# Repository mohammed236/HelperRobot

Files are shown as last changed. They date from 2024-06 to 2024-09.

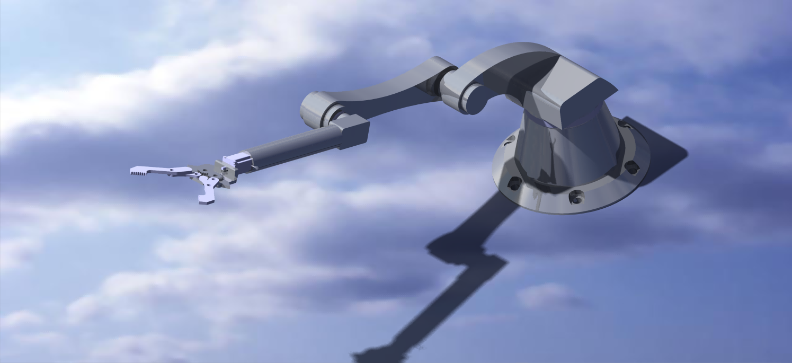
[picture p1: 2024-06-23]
Assets for Presentation/Systeme Image 2.tif

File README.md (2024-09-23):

# HelperRobot
Building a robot that can perform different tasks in various use cases.

# About
This project is a BTS graduation project. As mechanical product designers, we had to create a mechatronic mechanism to enhance our knowledge.

# Help
This project contains different file extensions for various software used. You will need:
* Microsoft Word
* Gantt, Trello, Excel
* Catia V5
* WonderShare EdrawMax
* Proteus
* Arduino IDE 2.0.3

# Note
This project is not completed.

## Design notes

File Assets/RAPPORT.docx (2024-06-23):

I. Analyse Fonctionnelle :

II. Analyse statique :

L’étude statique c’est l’étude des solides au repos (stable) pour un temps donné. Cette étude sert à déterminer les couples nécessaires pour actionner les articulations de notre bras manipulateur aussi que les efforts et les moments exercé au niveau du chaque articulations.

1. Schéma cinématique :

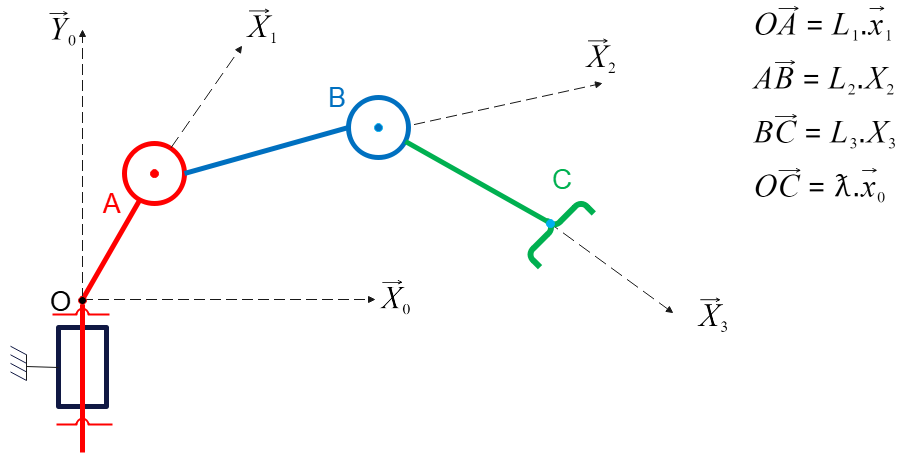
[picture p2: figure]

Repère | Solide | Paramètre | Dimension
0 | Châssis | XXXX | XXXX
1 | Bras articulé 1 | 0< θ_1 <360 | 90 mm
2 | Bras articulé 2 | -70< θ_2 <180 | 124 mm
3 | Bras articulé 3 | -160< θ_3 <160 | 135 mm

2. Les figures planes :

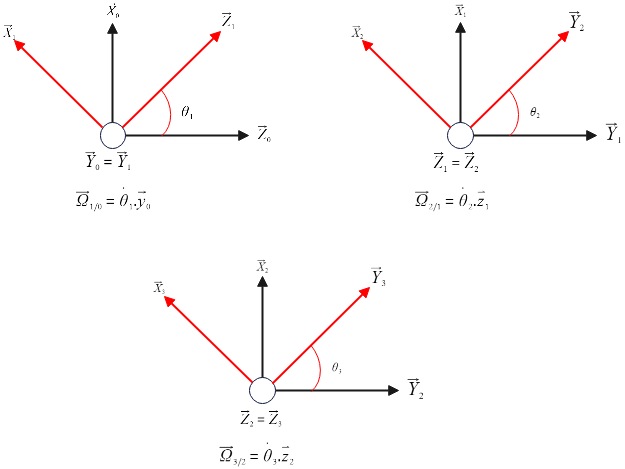
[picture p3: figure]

3. Graphe de structure :

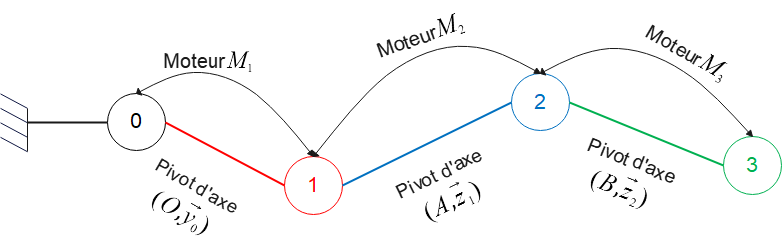
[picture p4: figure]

4. Hyperstatisme :

L'hyperstatisme, également connu sous le terme d'hyperstaticité ou de redondance statique, se réfère à une situation dans laquelle une structure possède plus de contraintes externes ou internes qu'il n'est nécessaire pour maintenir son équilibre statique. En d'autres termes, c'est une situation où il y a plus de liaisons ou de supports que ce qui est strictement nécessaire pour garantir la stabilité et la rigidité de la structure.

4.1. Objectifs et Avantages de l'Hyperstatisme :

4.1.1. Redondance Structurelle :

- Sécurité : En cas de défaillance d'un ou plusieurs éléments, la structure peut encore rester stable et en sécurité grâce aux liaisons supplémentaires. Cela est particulièrement important dans les ponts, les bâtiments et d'autres infrastructures critiques.

- Durabilité : Les structures hyperstatiques répartissent les charges de manière plus uniforme, réduisant les concentrations de stress et prolongeant ainsi la durée de vie des matériaux.

4.1.2. Rigidité Accrue :

- Déformations Réduites : Les structures hyperstatiques tendent à être plus rigides et moins sujettes aux déformations sous des charges, ce qui est crucial pour maintenir la fonctionnalité et l'intégrité de la structure.

4.1.3. Optimisation des Matériaux :

- Efficacité Matérielle : En concevant des structures hyperstatiques, les ingénieurs peuvent souvent utiliser les matériaux de manière plus efficace, répartissant les charges de manière à minimiser l'utilisation de matériaux tout en maximisant la performance structurale.

4.2. Exemples d'Applications :

4.2.1. Ponts : Les ponts sont souvent conçus avec une redondance statique pour garantir qu'ils restent en place même si une partie de la structure subit des dommages.

4.2.2. Bâtiments : Les gratte-ciels et autres grandes structures intègrent souvent des éléments hyperstatiques pour assurer leur stabilité face aux vents, aux tremblements de terre et à d'autres forces dynamiques.

4.2.3. Aéronautique : Dans les avions, la redondance est cruciale pour garantir la sécurité en cas de défaillance d'un composant.

En Résume :

L'hyperstatisme est une approche de conception qui vise à améliorer la sécurité, la durabilité et la performance des structures en ajoutant des liaisons ou des supports supplémentaires au-delà de ce qui est strictement nécessaire pour l'équilibre statique. Cela permet de créer des structures plus robustes, capables de résister à des défaillances locales sans compromettre leur intégrité globale.

4.3. Calcule de l'hyperstatisme :

L'hyperstatisme se calcule en examinant la différence entre les contraintes introduites par les moteurs et les degrés de liberté nécessaires pour un mouvement indépendant.

- Si m est la mobilité de system, alors : m = Mu + Mi = 3 + 0 = 3

Alors, m = 3

- L'hyperstatisme H peut être calculé comme :

H = Is – 6 * (nb pieces hors bati) + m

H = 15 – 6 * 3 + 3

H = 15 – 18 + 3 = 0

Donc, H = 0

Dans ce cas, le système n'est pas hyperstatique. Si H était supérieur à zéro, cela indiquerait un système hyperstatique (redondance statique).

### Ce résultat est confirmé par le fait que tous les systèmes ouverts sont isostatiques.

### 4.3.1 Conclusion

Le système décrit ici est isostatique avec H=0, ce qui signifie qu'il est exactement déterminé avec le nombre de moteurs et d'articulations disponibles.

### 4.4. mouvement de la pince / analyse cinématique

### 4.4.1 détermination de loi entrer sotie du système

### Pour monter la méthode de détermination de loi entrer sotie du system, on va d’abord simplifier le system comme suivant :

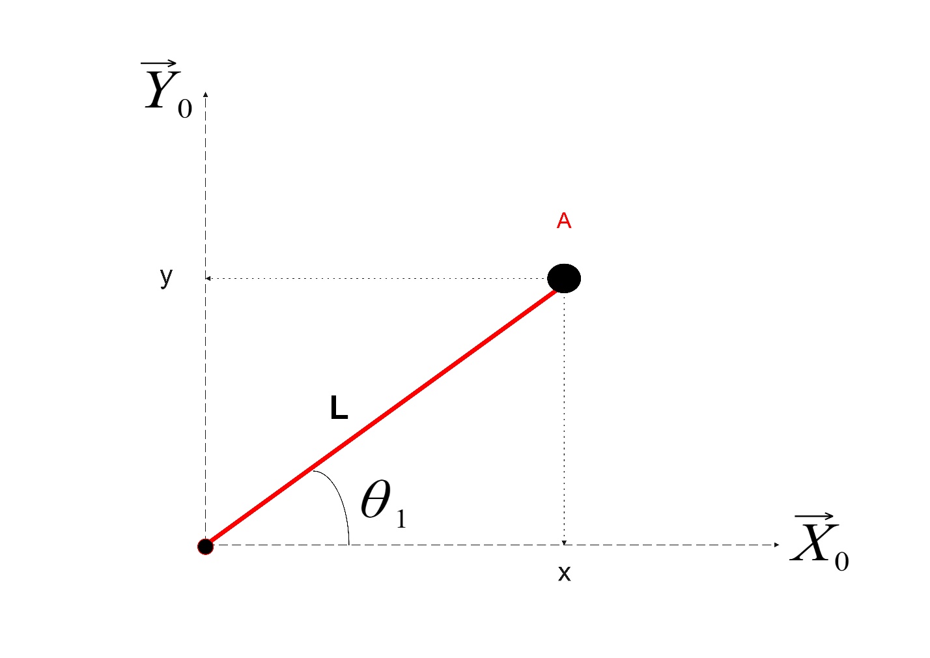
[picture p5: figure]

### En va prendre deux équations de cette figure pour déterminer l’angle θ1 par laquelle le point A sera déplacer.

### Première équation :

### L^2 = x^2 + y^2

### L= √(x^2 +y^2)

### Deuxième équation :

### tanθ1= y/x

### θ1= tan^(-1) y/x

### L’utilité de la première équation dans ce cas est de vérifier que la position a atteindre et ce qui il est dans la zone du bras ou non.

### Par exemple :

### On demande que le point A se déplace vers (30 ,10), avec la langueur du bras est

### L = 5

### Pour vérifier la position désirée on calcule :

### ( √(30^2 +10^2)<= 5 ) ?

### Si oui donc on peut se déplace et le point est dans la zone de déplacement du bras.

### Si non donc le point est hors la zone de déplacement du bras.

### Alors par la même approche en va ajouter un deuxième bras dans la figure comme dans la figure ci-dessous et pour simplifier L’étude on prendre que

### (L2 = L3) de notre system :

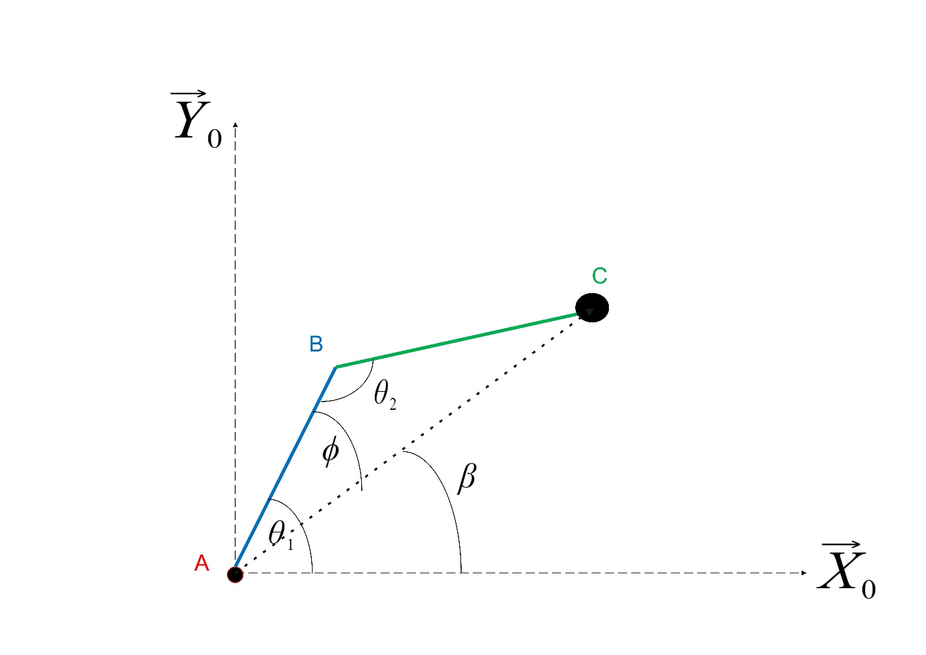
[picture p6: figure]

### Cette figure nos donnera les équations suivantes :

### tanβ= y/x

### β= tan^(-1) y/x

### Et on a d’après la loi de cosinus :

### L2^2 =L1^2 +L^2 -2L1.L.cosϕ

### cosϕ= (L1^2 +L^2 - L2^2)/(2L1.L)

### ϕ= cos^(-1) (L1^2 +L^2 - L2^2)/(2L1.L)

Alors :

Θ1 = ϕ + β = cos^(-1) (L1^2 +L^2 - L2^2)/(2L1.L)+ tan^(-1) y/x

Et On a de même :

L^2 =L1^2 +L2^2 -2L1.L2.cosΘ2

### cosΘ2= (L1^2 -L^2 + L2^2)/(2L1.L2)

### Θ2= cos^(-1) (L1^2 -L^2 + L2^2)/(2L1.L2)

### Finalement : {, Θ1= cos^(-1) (L1^2 +L^2 - L2^2)/(2L1.L)+ tan^(-1) y/x, Θ2 = cos^(-1) (L1^2 -L^2 + L2^2)/(2L1.L2)

Maintenant on a les valeurs nécessaires pour déplacer la pince par des angles effectuer par des moteurs.
mais dans notre cas on a le premier bras est fixe sur le bâti par un angle K1 dans l’axe Z. et ce bras effectuer une rotation sur l’axe Y commandée par un moteur d’angle Θ0 (voir figure ci-dessous).

et pour ajouter le premier bras dans notre analyse en vas traiter la premier plan (X, Y) comme suivant :

Le premier bras dans ce system est considérer comme un déplacement du repère du deux bras 1 et 2 par rapport au repère R0.
Alors pour trouver les relations finales des paramètres d’enter pour le déplacement de pince sur le plan (X, Y), il suffit de soustraire les coordonner de position de la pince et les coordonner du point A du system pour se retourner dans le cas étudie précédent.
avec cette approche la seule variable qui sera changée est le module L du système.

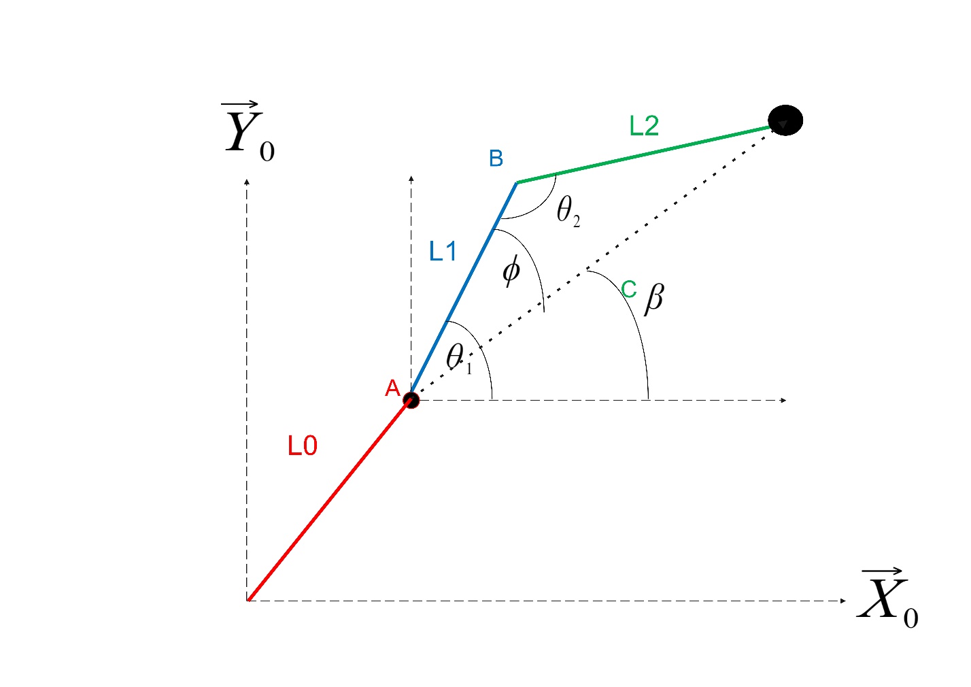
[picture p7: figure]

### On pose (Xi, Yi) les coordonner du point A, et (x, y) sont les coordonner de la pince, et que le premier bras est orienté par 65 dégrée sur l’axe Z donc :

### Xi=L0.cos65

### Yi=L0.sin65

### Alors :

### L= √((x-Xi)^2 +(y-Yi)^2)

### Maintenant il suffit de trouver l’angle Θ0 pour compléter notre étude sur la Cinématique Inversée de la pince.

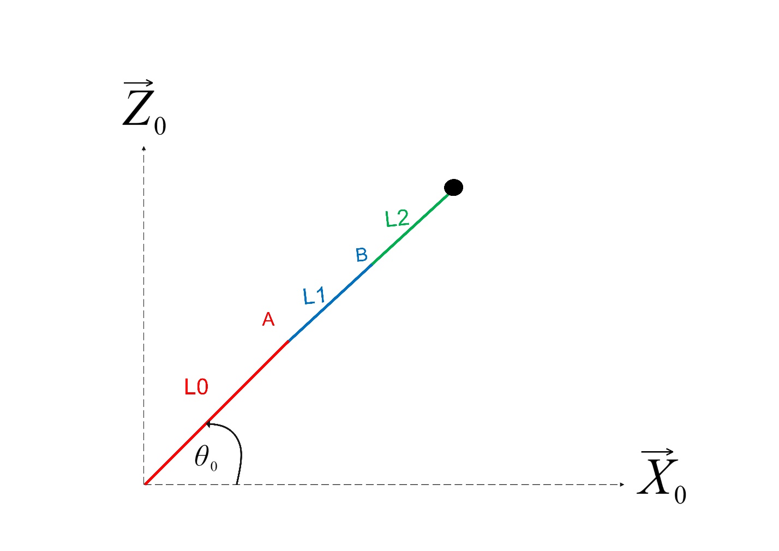
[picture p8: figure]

On a :
tanΘ0=Z/X

Θ0= tan^(-1) Z/X

Finalement la relation entre (x, y) et ( Θ0, Θ1, Θ2 ) est :
{, Θ0 = tan^(-1) Z/X , Θ1= cos^(-1) (L1^2 +L^2 - L2^2)/(2L1.L)+ tan^(-1) y/x, Θ2 = cos^(-1) (L1^2 -L^2 + L2^2)/(2L1.L2)

### 5. Étude dynamique :

### Pour contrôler les bras en va utiliser des actionneurs, et pour trouver l’actionneur parfait en va faire une étude dynamique sur notre système.

### La dynamique est la branche de la mécanique qui étudie le mouvement des corps sous l'action des forces. Elle combine les aspects de la cinématique et de la cinétique.

### Et sont Objective est Analyser et prédire le mouvement des corps en tenant compte des forces et des moments qui les affectent.

### 5.1. Détermination de couple :

### Pour commander un bras, un couple est nécessaire pour le faire, Ducoup en va déterminer les couples nécessaires pour chaque bras mobile.

### Et pour commencer l’étude un cahier de charge est nécessaire,

### En prend le cahier de charge défini au début de l’étude comme suivant :

Bras | Longueur | Masse (Charge associe au bras inclut)
Bras articulé 0 | L0 = 0.3m | M0 = 0.2 kg
Bras articulé 1 | L1 = 0.2m | M1 = 0.15 kg
Bras articulé 2 | L2 = 0.2m | M2 = 0.15 kg
Charge | XXXX | Mc = 5kg
Gravité | XXXX | G = 9.81 m⋅s−2

### 5.1.1. Détermination de couple remmené sur l’axe de la Bras articulé 2 :

### On a :

### F_(charge) =mc.g = 5*9.81=49.05 N=50 N

### Couple_(charge) =F_(charge) *L_2 =50*0.2=10 N.m^2

### Couple_(bras) =m_2 *g*(L_2)/2=0.15*9.81*0.1=0.15 N.m^2

Alors le couple remmené sur l’axe de la Bras articulé 2 est :

### Couple_(bras articulé 1) =Couple_(charge) + Couple_(bras) =10+0.15=10.15 N.m^2

### Couple_(bras articulé 2) =11 N.m^2

### 5.1.2. Détermination de couple remmené sur l’axe de la Bras articulé 1 :

### On a :

### F_(charge) =(mc+m_0 ).g = (5+0.2)*9.81=51.012 N=52 N

### Couple_(charge) =F_(charge) *L_1 =52*0.2=10.4 N.m^2

### Couple_(charge) =11 N.m^2

### Couple_(bras) =m_1 *g*(L_1)/2=0.15*9.81*0.1=0.15 N.m^2

### Alors le couple remmené sur l’axe de la Bras articulé 1 est :

### Couple_(bras articulé 1) =Couple_(charge) + Couple_(bras) =11+0.15=11.15 N.m^2

### Couple_(bras articulé 1) =12 N.m^2

### 5.1.3. Détermination de couple remmené sur l’axe de la Bras articulé 0 :

### On a :

### F_(charge) =(mc+ m_1 +m_2 ).g=(5+0.15+0.15)*9.81

### =51.993 N

### F_(charge) =53N

### Couple_(charge) =F_(charge) *L_0 =53*0.3=15.9 N.m^2

### Couple_(charge) =16 N.m^2

### Couple_(bras) =m_0 *g*(L_0)/2=0.2*9.81*0.15=0.3 N.m^2

### Alors le couple remmené sur l’axe de la Bras articulé 0 est :

### Couple_(bras articulé 1) =Couple_(charge) + Couple_(bras) =16+0.3=16.3 N.m^2

### Couple_(bras articulé 0) =17 N.m^2

### Finalement le couple nécessaire pour chaque bras pour la commander en rotation est :

### {, Couple_(bras articulé 0) =17 N.m^2 , Couple_(bras articulé 1) =12 N.m^2 , Couple_(bras articulé 2) =11 N.m^2

### 5.2. Détermination de vitesse de rotation :

### Comme il est mentionner sur le cahier de la charge on puera déplacer la charge par une vitesse constante de V = 0.2m/s.

### 5.2.1. Détermination de vitesse de rotation remmené sur l’axe de la Bras articulé 2 :

### On a :

### V=R* ω

### ω_2 =V/R= (V_(charge))/(L_2)= 0.2/0.2=1 rad/s

### 5.2.2. Détermination de vitesse de rotation remmené sur l’axe de la Bras articulé 1 :

### On a :

### V=R* ω

### ω_1 =V/R= (V_(charge))/(L_1)= 0.2/0.2=1 rad/s

### 5.2.1. Détermination de vitesse de rotation remmené sur l’axe de la Bras articulé 0 :

### On a :

### V=R* ω

### ω_0 =V/R= (V_(charge))/(L_0)= 0.2/0.3=0.6667 rad/s

### Finalement la vitesse de rotation nécessaire pour chaque bras pour la commander en rotation est :

### {, ω_0 =1 rad/s , ω_1 =1 rad/s , ω_2 =0.6667 rad/s

### 6. choix des Actionneurs :

### Les actionneurs sont des dispositifs qui convertissent une forme d'énergie en mouvement mécanique. Ils jouent un rôle crucial dans les systèmes automatisés en permettant le contrôle et le déplacement des composants mécaniques.

### Les actionneurs peuvent être classés en différentes catégories en fonction de l'énergie utilisée pour générer le mouvement : actionneurs électriques, actionneurs pneumatiques, actionneurs hydrauliques, et actionneurs piézoélectriques, entre autres.

### Parmi les actionneurs électriques, les moteurs pas à pas occupent une place importante en raison de leur précision et de leur contrôle facile.

### Les Moteurs Pas à Pas

### Dans notre système de commande on va utiliser les moteurs pas a pas pour des nombreuses raisons comme la précision et la commande des rotations par angle.

### Fonctionnement des Moteurs Pas à Pas

### Un moteur pas à pas est un type de moteur électrique qui divise une rotation complète en un nombre discret de pas. Chaque impulsion électrique appliquée au moteur correspond à un mouvement de rotation fixe, appelé "pas".

### Ce fonctionnement permet un contrôle précis de la position sans nécessiter de retour de position comme les systèmes à boucle fermée.

### Les moteurs pas à pas sont couramment utilisés dans les applications nécessitant un positionnement précis et répétable, telles que les imprimantes 3D, les scanners, les instruments médicaux, et les systèmes de commande numérique par ordinateur (CNC).

### Types de Moteurs Pas à Pas

### Il existe principalement trois types de moteurs pas à pas :

### 1. Moteurs pas à pas à réluctance variable :

### - Principe : Ils fonctionnent en utilisant des stators dentés et un rotor non magnétique. La rotation se produit lorsque le rotor est attiré par les dents du stator, en minimisant la réluctance du circuit magnétique.

### - Avantages : Construction simple et coût relativement bas.

### - Inconvénients : Moins de couple par rapport aux autres types de moteurs pas à pas.

### 2. Moteurs pas à pas à aimant permanent :

### - Principe : Ils possèdent un rotor aimanté et un stator avec des enroulements. Les impulsions électriques font tourner le rotor par attraction et répulsion magnétiques.

### - Avantages : Couple plus élevé et meilleure réactivité par rapport aux moteurs à réluctance variable.

### - Inconvénients : Construction plus complexe et coût plus élevé.

### 3. Moteurs pas à pas hybrides :

### - Principe : Ils combinent les caractéristiques des moteurs à réluctance variable et à aimant permanent. Le rotor est constitué de segments magnétiques et de dents, ce qui améliore la précision et le couple.

### - Avantages : Précision élevée, couple important et meilleur rendement.

### - Inconvénients : Coût plus élevé et construction plus complexe.

### Avantages et Inconvénients des Moteurs Pas à Pas

### Avantages :

### - Précision : Capacité de diviser une rotation complète en un grand nombre de pas, permettant un contrôle précis de la position.

### - Contrôle simplifié : Pas besoin de capteurs de position pour le contrôle en boucle ouverte.

### - Réversibilité : Possibilité de maintenir la position sans consommation d'énergie supplémentaire.

### Inconvénients :

### - Couple limité : Généralement, les moteurs pas à pas ont un couple inférieur comparé aux moteurs à courant continu pour une taille similaire.

### - Perte de synchronisation : À des vitesses élevées ou sous des charges lourdes, il y a un risque de perte de pas.

### - Rendement énergétique : Moins efficace par rapport à d'autres types de moteurs électriques, en raison de la consommation d'énergie continue même en position statique.

### En conclusion, les moteurs pas à pas sont des composants essentiels pour des applications nécessitant un positionnement précis et une simplicité de contrôle. Le choix du type de moteur pas à pas est basée sur :

Charge et Couple: Détermination de le couple nécessaire pour déplacer la charge. Cela inclut la charge statique et dynamique, ainsi que les forces de frottement.

Fréquence de Rotation: Spécification de la vitesse à laquelle le moteur doit tourner. La vitesse est souvent mesurée en révolutions par minute (RPM).

Puissance: Calcule de la puissance nécessaire en fonction du couple et de la vitesse de rotation.

### Précision: Détermination de la précision requise en termes de pas angulaire du moteur.

### Et pour ça et d’après notre recherche sur le marcher on va choisi

### Ce Catalogue :

### Fabricants de Moteurs Pas à Pas :

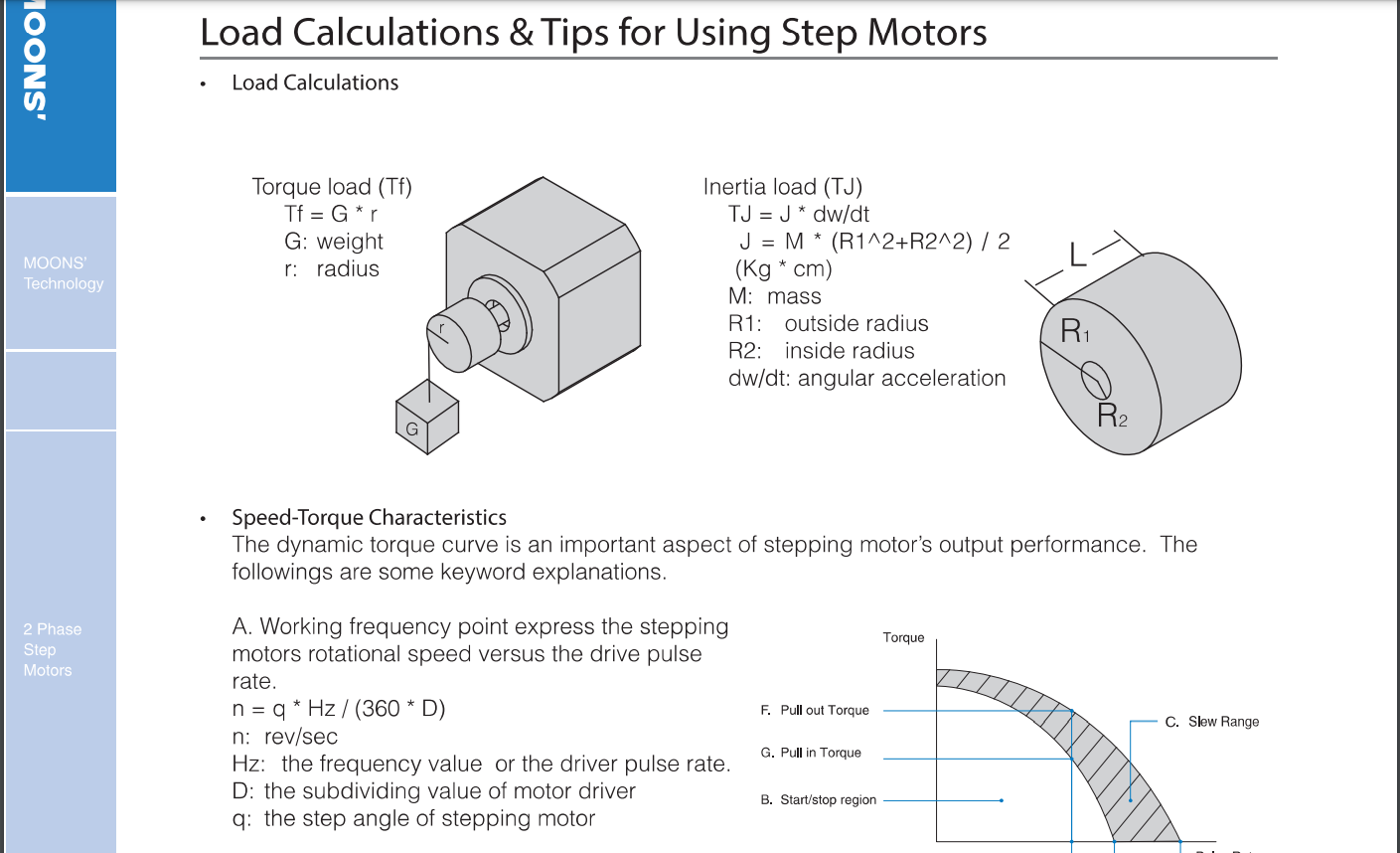
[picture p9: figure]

### Moons' Industries : Catalogue Moons' Industries

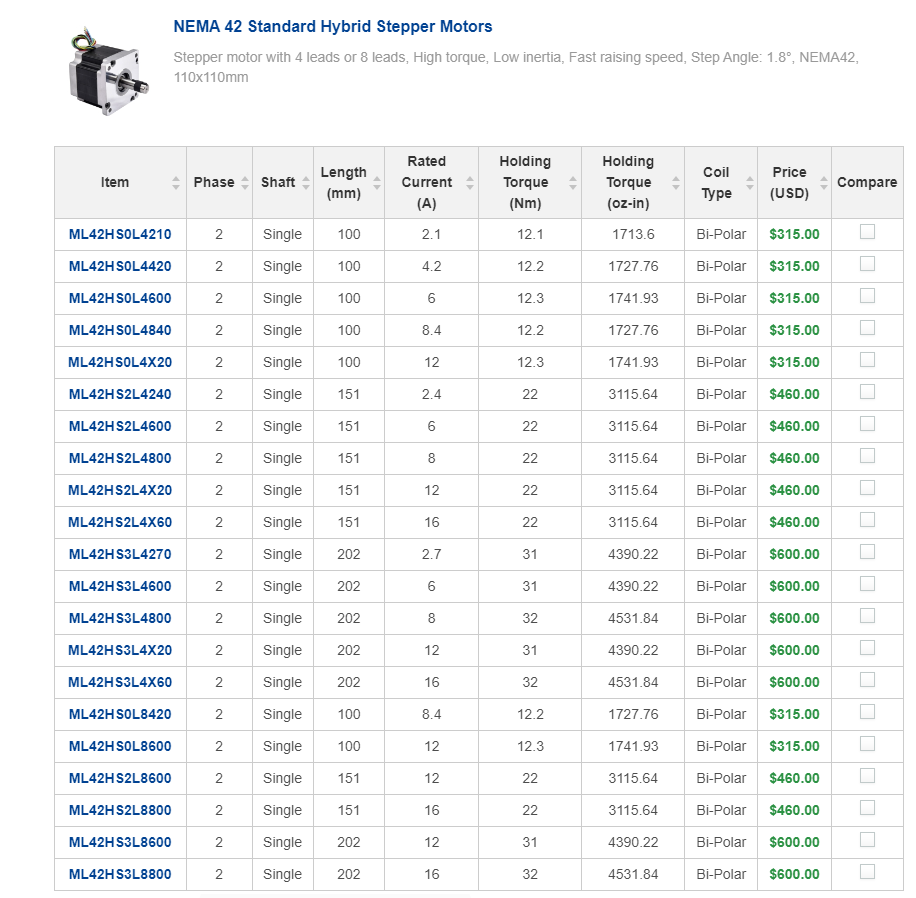
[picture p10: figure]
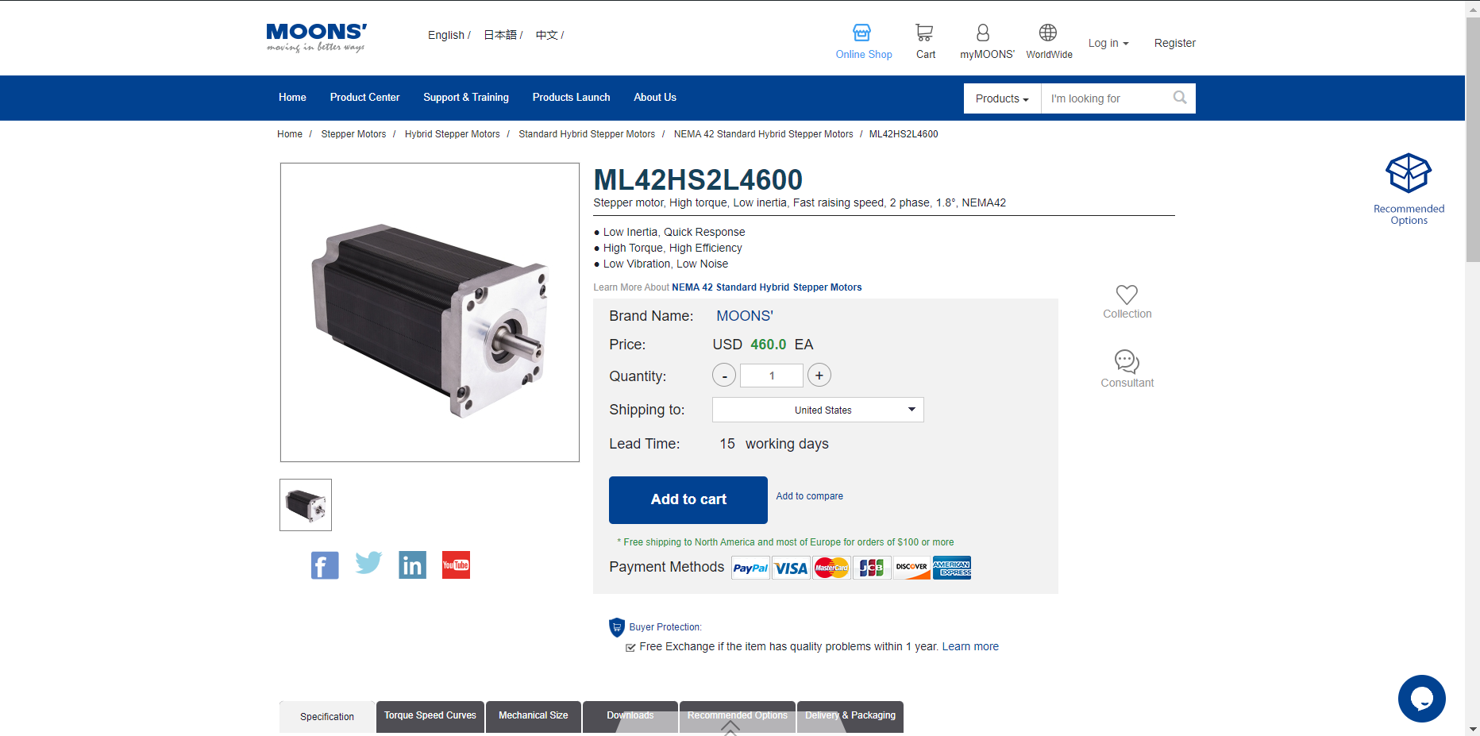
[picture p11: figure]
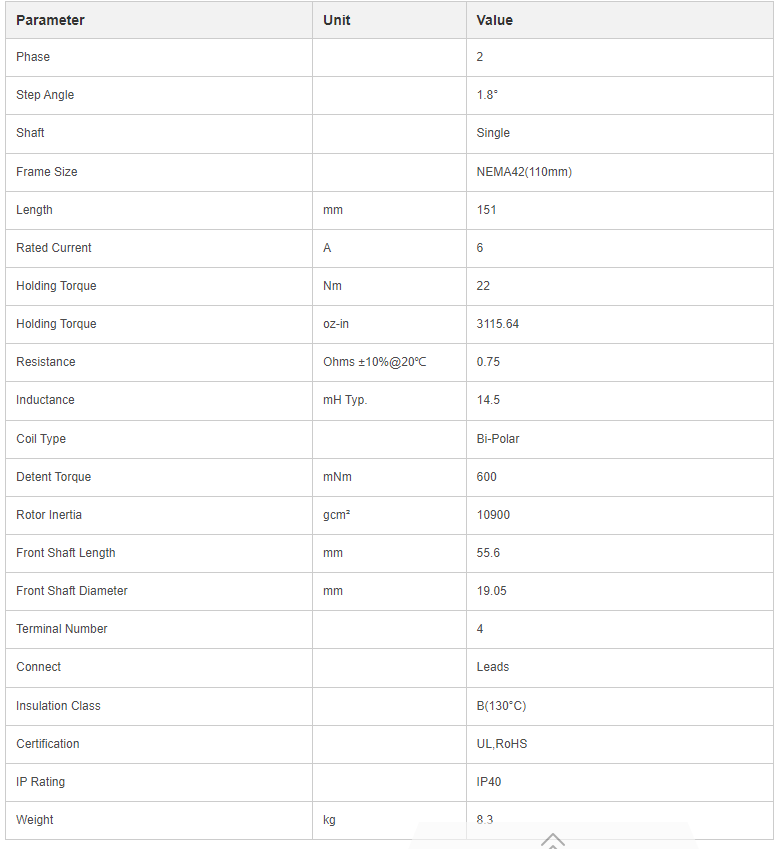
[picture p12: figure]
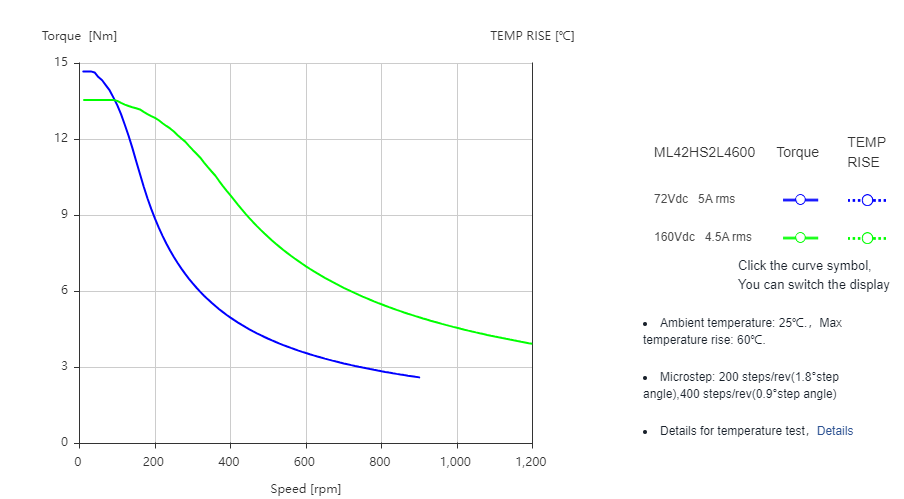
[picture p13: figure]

# Nous avons choisi le moteur pas a pas de référence ML42HS2L4600 pour commander l’angle Θ0 , Θ1 et Θ2

# Alors, on va commander 3 moteurs de même classe, Car sont caractéristiques est largement suffisant pour notre application.

### 6. Transformation de mouvement :

### La transformation de mouvement est le processus par lequel un type de mouvement est converti en un autre type de mouvement au sein d'un système mécanique. Cela est crucial dans de nombreux dispositifs mécaniques pour réaliser des tâches spécifiques.

### Les mécanismes utilisés pour la transformation de mouvement sont variés et incluent des dispositifs comme les leviers, les poulies, les engrenages, les bielles, et les cames. Voici quelques exemples courants de transformation de mouvement et les mécanismes associés :

### Transformation de mouvement rectiligne en mouvement rotatif :

### Mécanisme utilisé : Manivelle et bielle.

### Exemple :

### Dans un moteur à combustion interne, le mouvement rectiligne des pistons est transformé en mouvement rotatif du vilebrequin grâce à une bielle.

### Transformation de mouvement rotatif en mouvement rectiligne :

### Mécanisme utilisé : Vis sans fin et écrou.

### Exemple :

### Dans une presse mécanique, la rotation de la vis sans fin entraîne un écrou qui se déplace de manière linéaire, permettant ainsi de presser ou de soulever des objets.

### Transformation de mouvement rotatif en mouvement oscillatoire :

### Mécanisme utilisé : Came et levier.

### Exemple :

### Dans les machines à coudre, une came en rotation fait osciller une aiguille de haut en bas.

### Transformation de mouvement linéaire en mouvement oscillatoire :

### Mécanisme utilisé : Ressort et levier.

### Exemple :

### Dans les jouets mécaniques, un ressort tendu peut libérer son énergie pour faire osciller une partie du jouet.

### Transformation de mouvement rotatif en mouvement rotatif de vitesse différente :

### Mécanisme utilisé : Engrenages.

### Exemple :

### Les engrenages dans une boîte de vitesses d'une voiture permettent de changer la vitesse et la direction du mouvement rotatif provenant du moteur.

### Transformation de mouvement rotatif en mouvement rotatif:

### Mécanisme utilisé : Poulie et Courroie.

### Exemple :

### Dans une courroie de distribution d'un moteur de voiture, la courroie relie la poulie du vilebrequin à la poulie de l'arbre à cames, synchronisant leur mouvement rotatif.

### Pourquoi utiliser la transformation de mouvement ?

### Adaptation des tâches :

### Les différentes tâches mécaniques nécessitent différents types de mouvements. Par exemple, le déplacement d'un ascenseur nécessite un mouvement linéaire, tandis qu'un ventilateur nécessite un mouvement rotatif.

### Efficacité :

### La transformation de mouvement peut maximiser l'efficacité d'un système en utilisant le type de mouvement le plus approprié pour une tâche donnée.

### Contrôle et précision :

### Certains types de mouvement offrent un meilleur contrôle et une plus grande précision pour certaines applications. Par exemple, les cames permettent un contrôle précis des mouvements répétitifs.

### Conversion de puissance :

Dans de nombreux systèmes, il est nécessaire de convertir la puissance entre différents types de mouvements pour transmettre efficacement l'énergie. Par exemple, les transmissions de véhicules convertissent le mouvement rotatif à haute vitesse du moteur en un mouvement rotatif à basse vitesse mais à couple élevé pour les roues.

### Optimisation de l'espace :

### Les mécanismes de transformation de mouvement permettent de concevoir des systèmes plus compacts et plus légers en adaptant le type de mouvement aux contraintes de l'espace disponible.

### En résumé, la transformation de mouvement est une technique essentielle en ingénierie mécanique pour adapter, contrôler, et optimiser le mouvement et la puissance dans divers systèmes et dispositifs.

### Alors, puisque les moteurs de notre système ils sont placée dans une seule place loin de point d’application, et comme il est notée sur le cahier de la charge en va prend le système polie et Courroie comme solution technique pour transformer le mouvement.

### 6.1. Poulie et Courroie :

6.1.1. Fonctionnement :

- Poulie : Une poulie est une roue avec une gorge autour de son bord, qui permet à une corde, une courroie ou un câble de passer à travers elle. Une poulie simple change la direction de la force appliquée.
- Courroie : Une courroie est une bande flexible et continue de matériau (souvent en caoutchouc ou en matériau composite) qui transmet le mouvement rotatif entre deux ou plusieurs poulies.

6.1.2. Types de transformation de mouvement :

- Transformation de mouvement rotatif en mouvement rotatif : Les poulies et les courroies sont principalement utilisées pour transmettre un mouvement rotatif d'un arbre à un autre. Cela peut inclure le changement de direction, la modification de la vitesse, ou le changement du couple.
  - Exemple : Dans une courroie de distribution d'un moteur de voiture, la courroie relie la poulie du vilebrequin à la poulie de l'arbre à cames, synchronisant leur mouvement rotatif.

6.1.3. Types de poulies et courroies :

- Poulie simple : Utilisée pour changer la direction d'une force.
- Poulie fixe et mobile : Utilisées en combinaison pour créer des palans permettant de réduire l'effort nécessaire pour soulever des charges lourdes.
- Courroies plates : Utilisées pour les transmissions à longue distance et à grande vitesse.
- Courroies trapézoïdales (en V) : Offrent une meilleure adhérence et sont couramment utilisées dans les moteurs automobiles.
- Courroies crantées : Utilisées dans les systèmes nécessitant une synchronisation précise, comme les moteurs à combustion interne.

6.1.4. Avantages des poulies et des courroies :

- Efficacité de transmission : Elles peuvent transmettre de la puissance sur des distances plus longues par rapport aux engrenages.
- Flexibilité : Les courroies sont flexibles et peuvent absorber les chocs et les vibrations, réduisant l'usure des composants.
- Coût : Généralement moins coûteux et plus simples à installer et à entretenir par rapport à des systèmes d'engrenages complexes.
- Adaptabilité : Les systèmes de poulies et courroies peuvent facilement être ajustés ou modifiés pour répondre à des exigences spécifiques de vitesse ou de couple.

6.1.5. Applications courantes :

- Automobile : Transmission de la puissance du moteur aux différents composants comme l'alternateur, la pompe à eau, et la climatisation.
- Machines industrielles : Transmission de puissance dans les machines-outils, les convoyeurs, et autres équipements de production.
- Électroménagers : Utilisation dans les lave-linges, les sèche-linges, et autres appareils nécessitant des systèmes de transmission de puissance.

En résumé, les poulies et les courroies sont des mécanismes essentiels pour la transformation et la transmission du mouvement rotatif dans de nombreux systèmes mécaniques. Leur utilisation permet une transmission efficace de la puissance, une réduction des coûts, et une grande flexibilité dans la conception et l'entretien des machines.

6.2. Dimensionnement de Poulie et Courroie :

### Dissinuer le schemas …..

8. Partie Électrique et Électronique :

8.1. Dimensionnement de la Batterie :

Le dimensionnement de la batterie pour un bras robotique utilisant des moteurs pas à pas nécessite une analyse des besoins énergétiques de l'ensemble du système. On va détailler par la suite comment choisi la batterie adapter au notre application.

#### 1. Calcul des Besoins Énergétiques

a. Calcule de Courant et de Puissance des Moteurs Pas à Pas :

- Tension Nominale (V) : La tension d'alimentation des moteurs pas à pas, généralement spécifiée par le fabricant.
- Courant Nominal (I) : Le courant consommé par chaque moteur pas à pas, également spécifié par le fabricant.
- Puissance (P) : La puissance consommée par chaque moteur, calculée comme

P= V × I=9 ×6=54 W .

b. Estimation de Courant Total :

- Nombre de Moteurs (N) : Le nombre total de moteurs pas à pas dans le bras robotique.
- Courant Total( I_(total) ) : Le courant total consommé par tous les moteurs, calculé comme :

I_(total) =N*I=3*6=18 A

c. Déterminer le Temps de Fonctionnement :

- Temps de Fonctionnement par Jour (T) : Le temps total pendant lequel les moteurs seront en fonctionnement par jour, en heures.

Et d’après le cahier de charge on a T = 4h.

#### 2. Calculer la Capacité de la Batterie

a. Capacité Nécessaire (Ah) : La capacité de la batterie doit être suffisante pour alimenter les moteurs pendant le temps de fonctionnement prévu. Utilisez la formule suivante :

Capacité (Ah) = I_(total) × T = 18 × 4 = 72 Ah

b. Ajouter une Marge de Sécurité : Pour garantir que la batterie ne se décharge pas complètement, ajoutez une marge de sécurité, généralement entre 20% et 30% de la capacité calculée.

Capacité Final(Ah)= Capacité(Ah) × (1+Marge de Sécurité)

Capacité Final(Ah)= 72 × (1+0.25)=90 Ah

#### 3. Sélection de Type de Batterie

Les types de batteries couramment utilisés pour les systèmes robotiques sont :

- Batteries Li-ion (Lithium-ion) : Haute densité énergétique, recharge rapide, mais plus coûteuses.
- Batteries Li-Po (Lithium-Polymer) : Similaires aux Li-ion, mais avec une forme plus flexible et souvent utilisées dans les applications nécessitant des batteries légères.
- Batteries NiMH (Nickel-Metal Hydride) : Moins coûteuses mais avec une densité énergétique inférieure et un poids plus élevé.
- Batteries au plomb-acide : Très économiques, mais lourdes et volumineuses, et avec une durée de vie plus courte.

# Et finalement D’après une difficulté de trouver une batterie qui est d’un poids n’est pas très élevé, la PRLR-90 Lithium-Ion Battery est le choix convenable pour notre system.

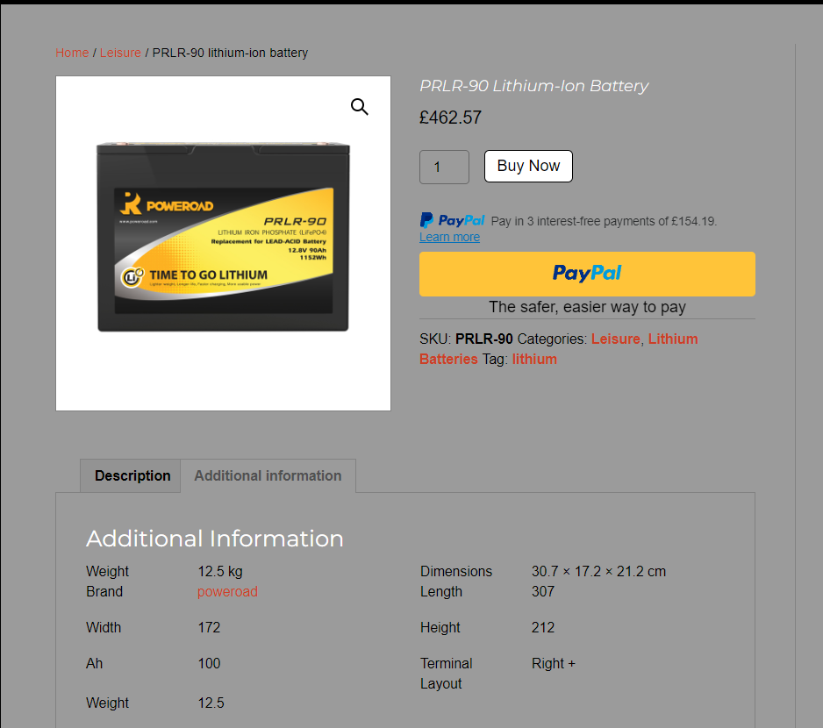
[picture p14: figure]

8.2. Schéma Électrique de la partie Opérative :

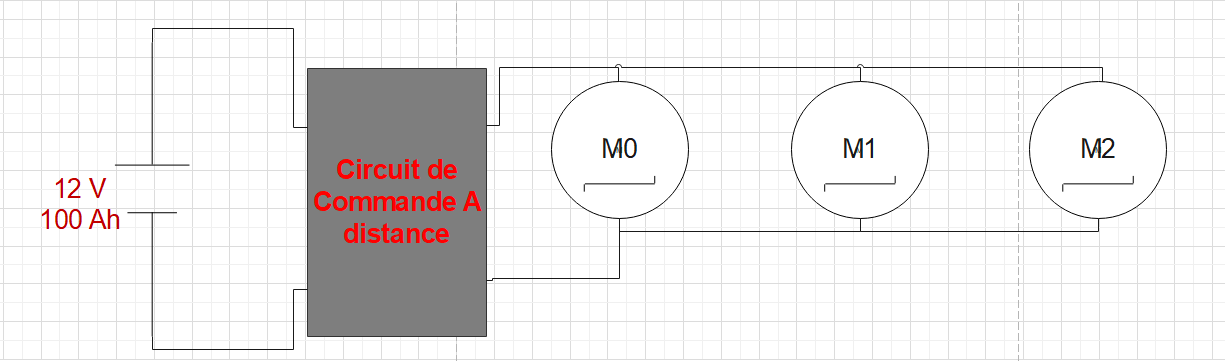
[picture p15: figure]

8.2. Schéma Électronique de la partie de commande :

Avec l’utilisation de la Site Web circuito, voir les composant de ce schéma : https://www.circuito.io/app?components=9238,9238,9238,9442,11021

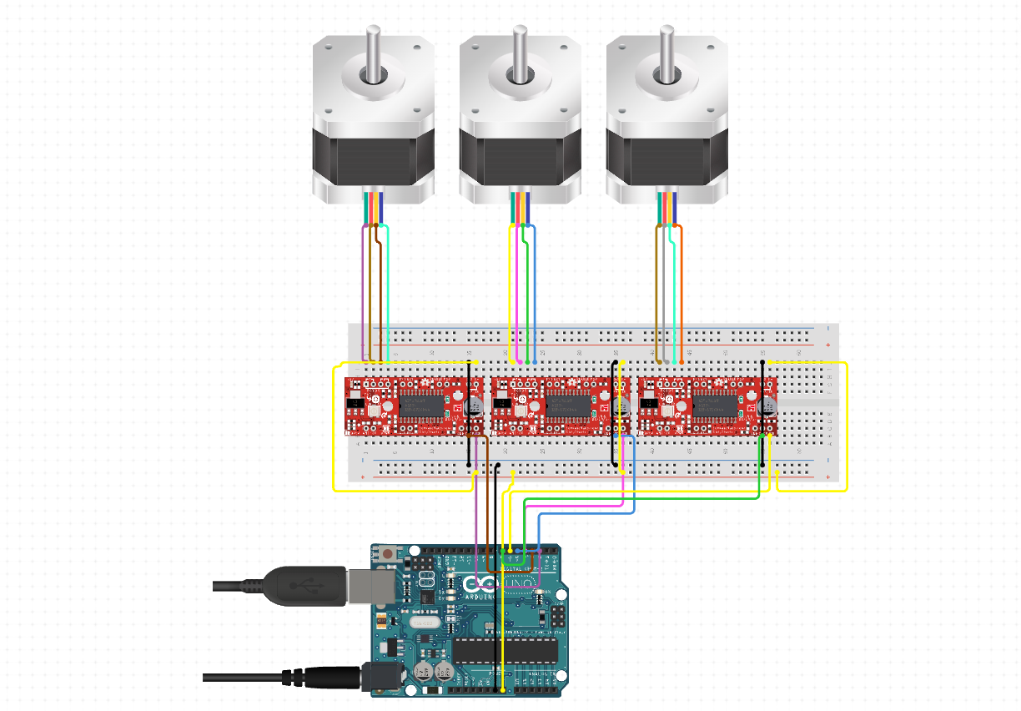
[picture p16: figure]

8.2. Commande de système par code :

Et pour Controller notre system, un code C++ sur Arduino doit être implémenter, on peut écrire le script comme ci-dessous pour régler l’angle désirée de Motors :

- Inclure la bibliothèque et définir les broches :

Nous incluons la bibliothèque AccelStepper et définissons les broches pour le pas et la direction de chaque moteur.

- Créer des objets moteurs :

Nous créons des objets AccelStepper pour chaque moteur en utilisant les broches définies.

- Fonction setup () :

Dans la fonction setup(), nous définissons la vitesse maximale et l'accélération pour chaque moteur. Ajustez ces valeurs en fonction des spécifications de vos moteurs.

#include <AccelStepper.h>

// Define motor interface type

#define MotorInterfaceType 1

// Define the pins for the motors

#define MOTOR1_STEP_PIN 2

#define MOTOR1_DIR_PIN 3

#define MOTOR2_STEP_PIN 4

#define MOTOR2_DIR_PIN 5

#define MOTOR3_STEP_PIN 6

#define MOTOR3_DIR_PIN 7

// Create motor objects

AccelStepper motor1(MotorInterfaceType, MOTOR1_STEP_PIN, MOTOR1_DIR_PIN);

AccelStepper motor2(MotorInterfaceType, MOTOR2_STEP_PIN, MOTOR2_DIR_PIN);

AccelStepper motor3(MotorInterfaceType, MOTOR3_STEP_PIN, MOTOR3_DIR_PIN);

// Steps per revolution for the stepper motors

const int stepsPerRevolution = 200; // This value depends on your stepper motor

// Robot arm parameters

const float L0_Angle = 65.0;

const float L0 = 0.3;

const float L1 = 0.2;

const float L2 = 0.2;

float xi, yi, L;

void setup() {

// Initialize the motors

motor1.setMaxSpeed(200);

motor1.setAcceleration(50);

motor2.setMaxSpeed(200);

motor2.setAcceleration(50);

motor3.setMaxSpeed(200);

motor3.setAcceleration(50);

// Start serial communication

Serial.begin(9600);

// Calculate initial xi and yi based on L0 and L0_Angle

xi = L0 * cos(L0_Angle * DEG_TO_RAD);

yi = L0 * sin(L0_Angle * DEG_TO_RAD);

}

void loop() {

// Check if data is available from the serial monitor

if (Serial.available() > 0) {

// Read the incoming string

String input = Serial.readStringUntil('\n');

Serial.println("Received: " + input); // For debugging purposes

// Parse the target coordinates from the input string

float x, y, z;

if (sscanf(input.c_str(), "%f,%f,%f", &x, &y, &z) == 3) {

// Calculate the angles and move the motors

goToNextPos(x, y, z);

// Send a confirmation message

Serial.println("Moved to: " + String(x) + ", " + String(y) + ", " + String(z));

} else {

// Send an error message if the input is not valid

Serial.println("Invalid input. Please send coordinates in the format: x,y,z");

}

}

}

// Function to calculate and move to the specified position

void goToNextPos(float x, float y, float z) {

L = sqrt(y * y + x * x);

if (L > L1 + L2) {

Serial.println("Out of ARM Scope");

return;

}

float k1 = (-L * L + L1 * L1 + L2 * L2) / (2 * L1 * L2);

float k2 = (L * L + L1 * L1 - L2 * L2) / (2 * L1 * L);

float gamma = atan2(x, z) * RAD_TO_DEG;

xi = L0 * cos((L0_Angle + gamma) * DEG_TO_RAD);

yi = L0 * sin((L0_Angle + gamma) * DEG_TO_RAD);

double alpha_2 = acos(k1) * RAD_TO_DEG;

double beta_1 = acos(k2) * RAD_TO_DEG;

double beta_2 = atan2(y, x) * RAD_TO_DEG;

double alpha_1 = beta_1 + beta_2;

Serial.println("Angles: " + String(alpha_1) + ", " + String(alpha_2) + ", " + String(gamma));

// Move the motors to the calculated angles

moveToAngles(alpha_1, alpha_2 - 180, gamma - 90);

}

// Function to convert degrees to steps

long degreesToSteps(float degrees) {

return (long)(degrees * stepsPerRevolution / 360.0);

}

// Function to move motors to specified angles

void moveToAngles(float angle1, float angle2, float angle3) {

long target1 = degreesToSteps(angle1);

long target2 = degreesToSteps(angle2);

long target3 = degreesToSteps(angle3);

motor1.moveTo(target1);

motor2.moveTo(target2);

motor3.moveTo(target3);

// Wait for the motors to reach their positions

while (motor1.isRunning() || motor2.isRunning() || motor3.isRunning()) {

motor1.run();

motor2.run();

motor3.run();

}

}

Et par la suite de l’étude on peut ajouter la fonctionnalité Bluetooth ou Wifi pour Controller notre système a distance, mais pour le moment on va s’arrêter a se nivaux pour ne pas compliquer les choses.

8.2. Conception sur logiciel Catia V5 :

CATIA (Computer-Aided Three-Dimensional Interactive Application) est un logiciel de conception assistée par ordinateur (CAO) largement utilisé dans l'industrie pour la modélisation 3D, la conception de produits et l'ingénierie. La conception d'un extracteur de roulement sur CATIA implique plusieurs étapes, allant de la création du modèle 3D à la génération des plans détaillés pour la fabrication.

- Quelque Généralité sur Catia

1- Quelque Raccourcis :

Escape | Abort the current process or exit the current dialog box (when there is one)
F1 | Open Help
F3 | Structure tree out or insert (Toggle specification tree display on and off)
F9 | Toggle Hide/Show
F10 | Toggle Swap Visible Space
Shift+F1 | Context assistance (Get help on toolbar icons)
Shift+F2 | Toggle the specification tree overview on and offopens an overview on specifications tree in a new window.
Shift+F3 | Structure tree activate around e.g. character size to modify (activate the graph if the model is active and inversely)
Shift+Arrow Left/ Shift+Arrow Right | Rotate to the left / rotate to the right
Shift+Arrow Up/ Shift+Arrow Down | Rotate upward / rotate downward
Alt+F8 | Macros start
Alt+F11 | Visual basic wordprocessor
Home | Display the top of the graph
End | Display the bottom of the graph
Ctrl+Page Up/Ctrl+Page Down | Zoom in / zoom out the model or tree whichever is active
Ctrl+Arrow Right/ Ctrl+Arrow Left | Pan model to the right pan / pan model to the left
Ctrl+Arrow Up/ Ctrl+Arrow Down | Pan model to the top / pan model to the bottom
CTRL +Shift+Arrow Right / Ctrl+Shift+ Arrow Left | Rotate the model clockwise / rotate model counter-clockwise around Z axis
Ctrl+Tab | Switch between the different windows
Ctrl+N | New document
Ctrl+O | Open document
Ctrl+S | Save document
Ctrl+P | Print document
Ctrl+F | Find/ Search
Ctrl+U | Update
Ctrl+X/Ctrl+C/Ctrl+V | Cut / Copy / Paste
Ctrl+Z | Undo
Ctrl+Y | Redo
Ctrl+F11 | Go to Preselection Navigator
Page Up/Page Down | Relocate graph one page up / relocate graph one page down
Arrow Up/Arrow Down | Relocate the graph 1/10th of a page to the top / to the bottom
Arrow Left/Arrow Right | Relocate the graph 1/10th of a page to the left / to the right
Alt+Enter | Properties
Alt+Shift+ Arrow Left | ROTATE the model
Ctrl+D | Activate fast multi-instantiation tool in assembly design workbench
Ctrl+E | Activate define multi-instantiation tool in assembly design workbench

2- Composants de l’interface

Lorsqu’un atelier ou un module de CATIA V5 est activé, l’interface est sensiblement identique à celle-ci :

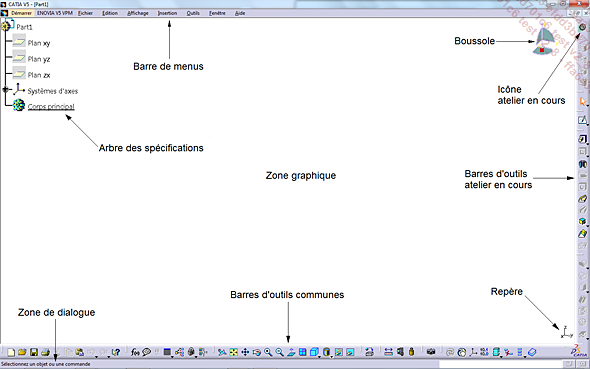
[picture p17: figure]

- Barre de menus

La barre des menus affichée ci-dessous permet d’enregistrer des fichiers, de les ouvrir, de les fermer et de réaliser des actions en fonction de l’atelier activé :

- Barres d’outils et boutons

Les barres d’outils contiennent les fonctions nécessaires à la réalisation de documents générés par CATIA V5.

Certaines barres d’outils diffèrent selon l’atelier actif. Elles peuvent être affichées ou masquées via le menu Affichage - Barres d’outils représenté ci-dessous.

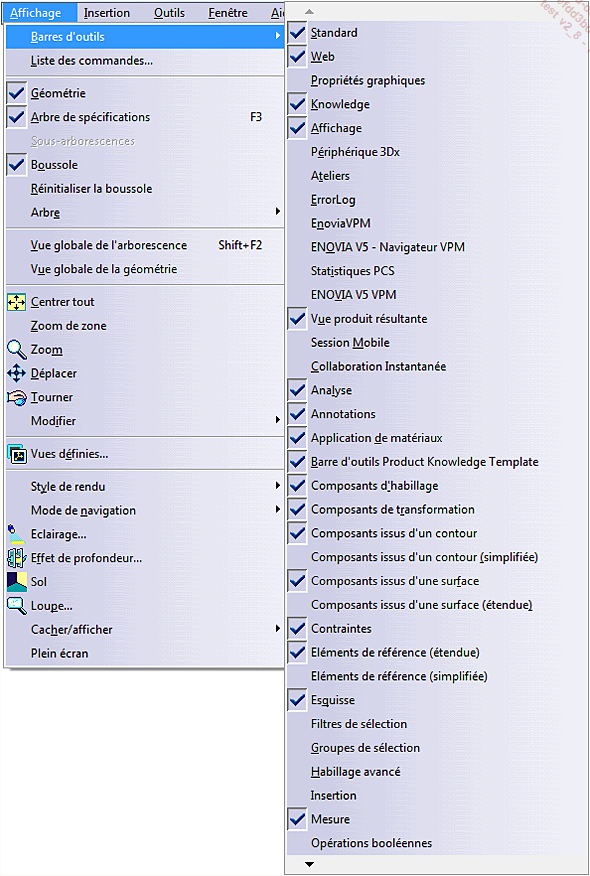
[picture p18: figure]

Toutes les commandes sont également accessibles par la barre de menus située au-dessus de la zone graphique.

Lorsque l’espace est insuffisant dans les bandeaux situés autour de la zone graphique, il est possible que certaines barres d’outils soient masquées. Dans ce cas, une double flèche située dans le coin inférieur droit de la fenêtre d’application CATIA V5 permet d’afficher la barre d’outils.

Pour afficher les barres d’outils, effectuez un cliqué-glissé sur une des doubles flèches vers la zone graphique.

a. Les barres d’outils communes

Elles sont présentes en permanence quel que soit l’atelier actif, comme affichées ci-dessous :

b. Les barres d’outils de l’atelier en cours

Leur affichage dépend de l’atelier en cours.

Elles comportent des barres d’outils simples et des barres d’outils contextuelles.

Les figures suivantes représentent les interfaces des ateliers Esquisse et Part Design et les barres d’outils associées.

Atelier Esquisse :

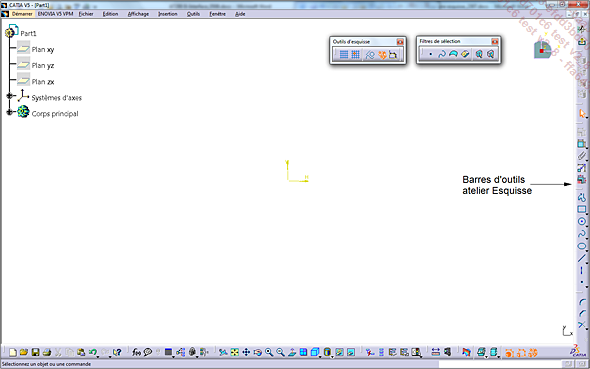
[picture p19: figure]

Atelier PartDesign:

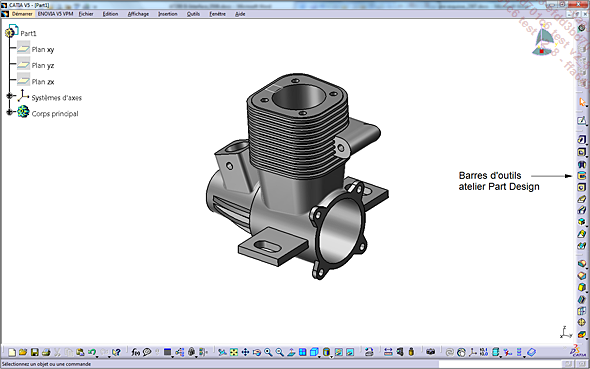
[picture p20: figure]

c. Les barres d’outils contextuelles

Les icônes déroulantes (ou à flèche) donnent accès aux barres d’outils contextuelles.

Pour afficher une barre d’outils contextuelle (ici la barre d’outils Droite), cliquez sur la flèche noire de l’icône Droite .

L’icône affichée est celle de la dernière fonction utilisée.

La barre d’outils s’affiche alors comme suit :

Pour déplacer la barre d’outils, effectuez un cliquer-glisser sur la poignée de la barre d’outils (représentée ci-dessous)

**NOTE** :

Pour une révision approfondie sur le logiciel je recommande de visiter ce livre :
https://www.editions-eni.fr/livre/catia-v5-mechanical-design-9782746094994/creer-une-esquisse

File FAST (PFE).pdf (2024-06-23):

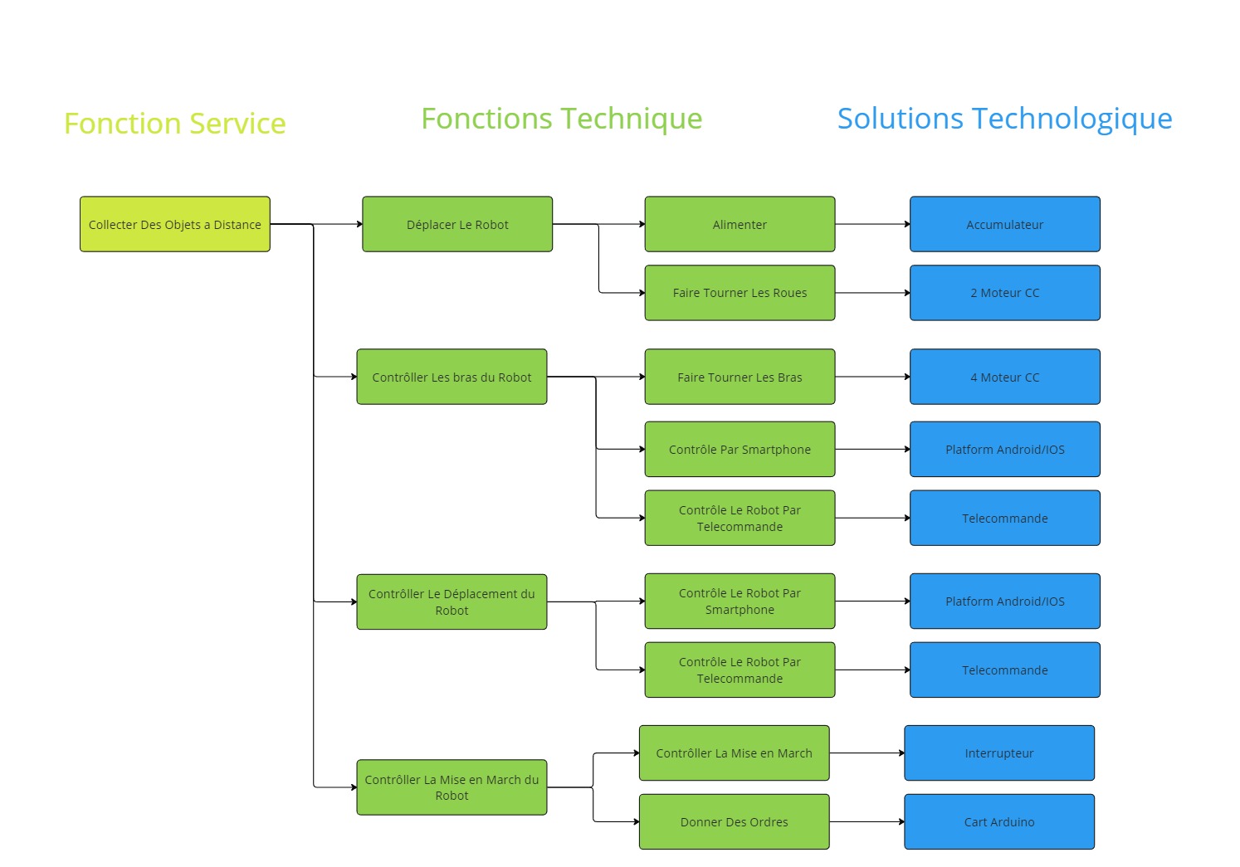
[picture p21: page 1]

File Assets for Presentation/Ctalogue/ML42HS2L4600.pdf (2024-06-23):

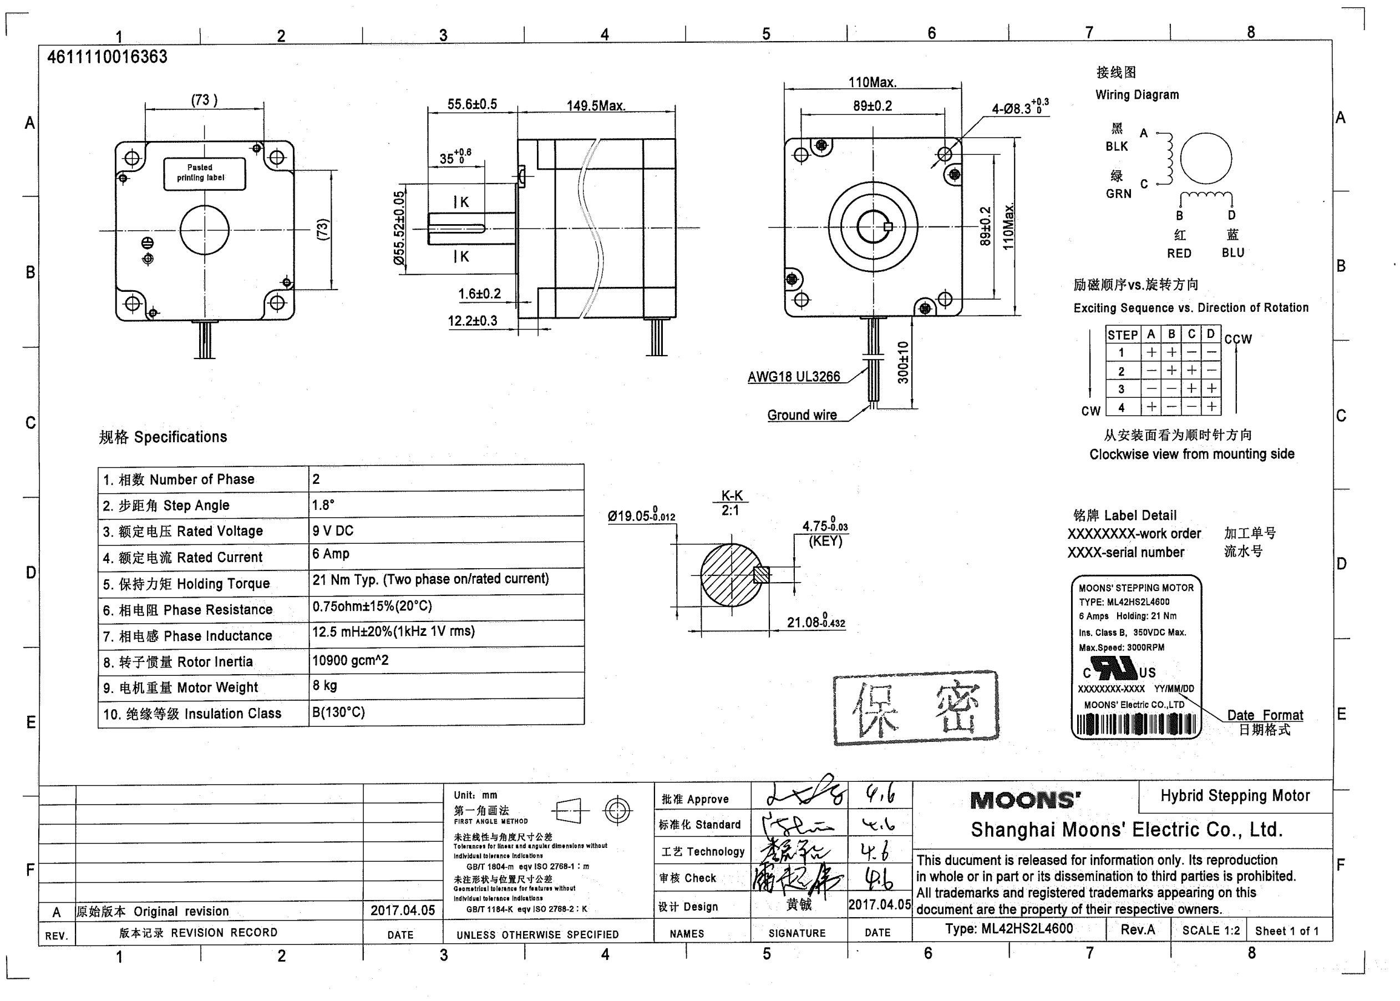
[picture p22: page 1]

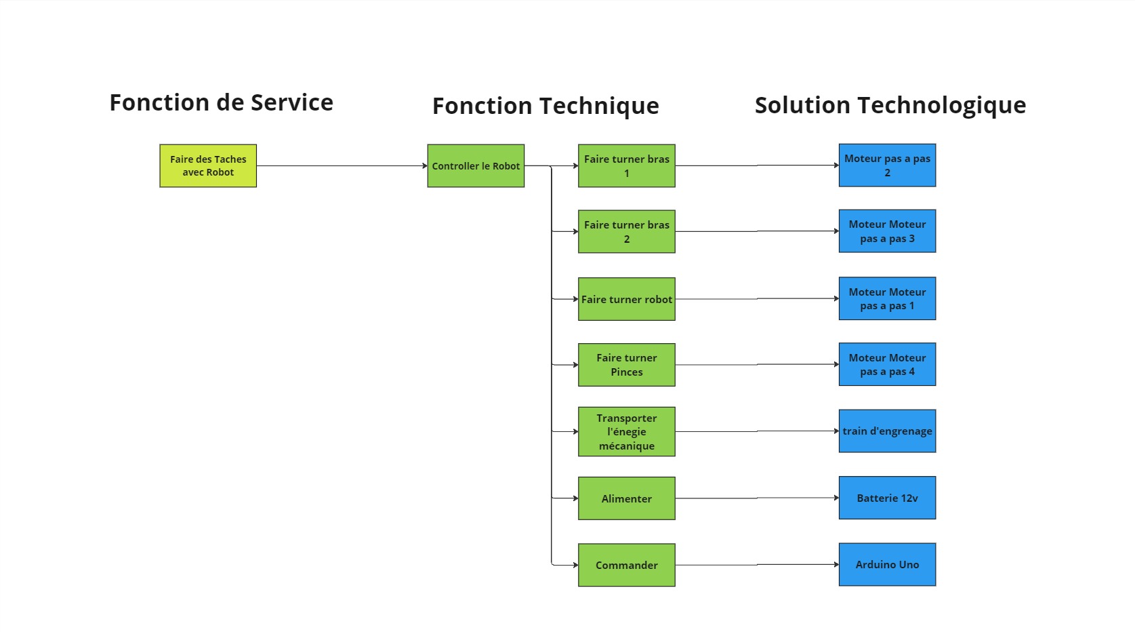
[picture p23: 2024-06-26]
Fast 2.jpg

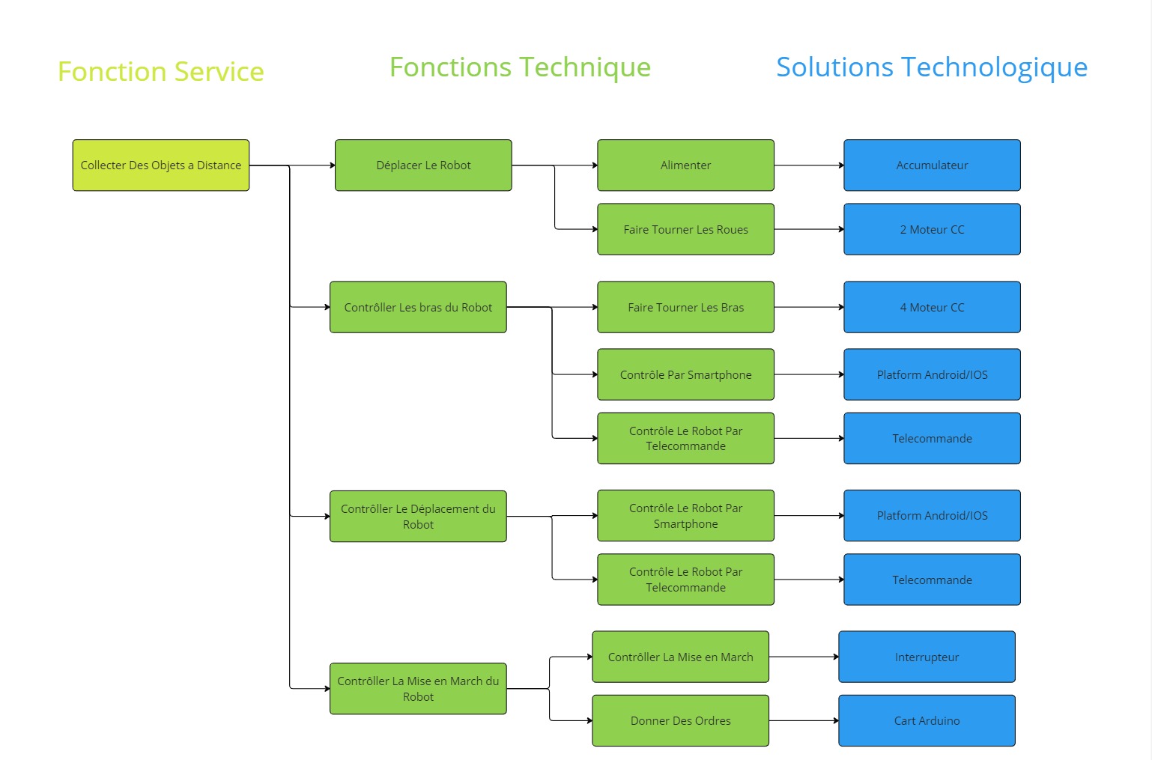
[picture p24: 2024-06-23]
FAST (PFE).jpg

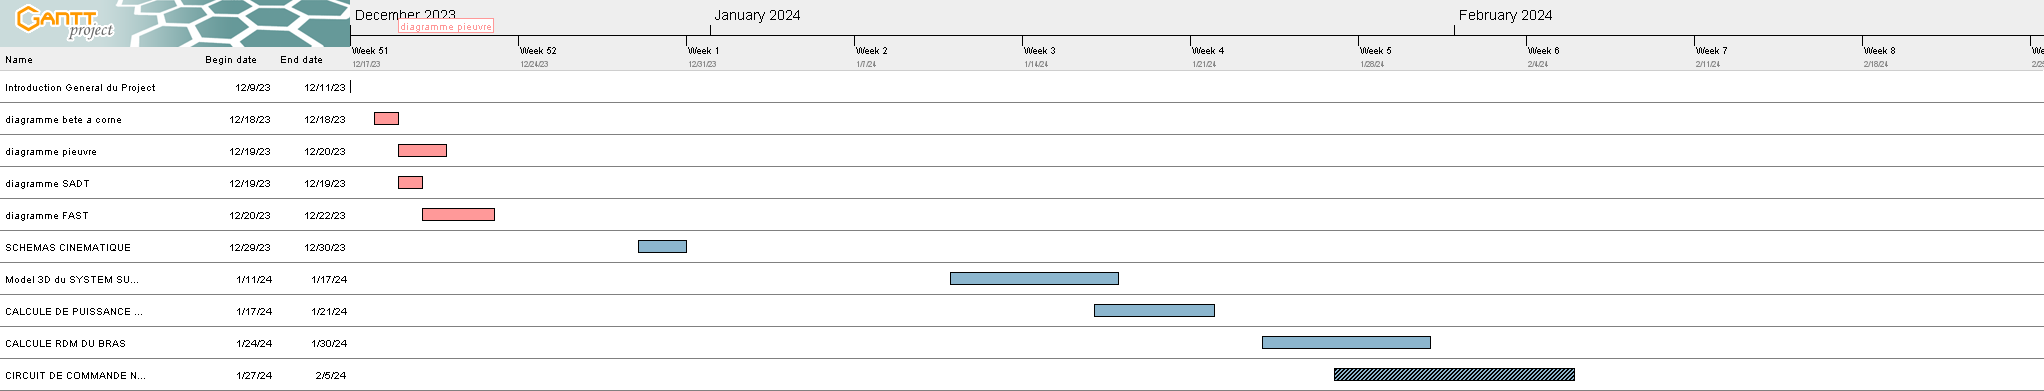
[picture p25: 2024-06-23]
PFE Project 1.png

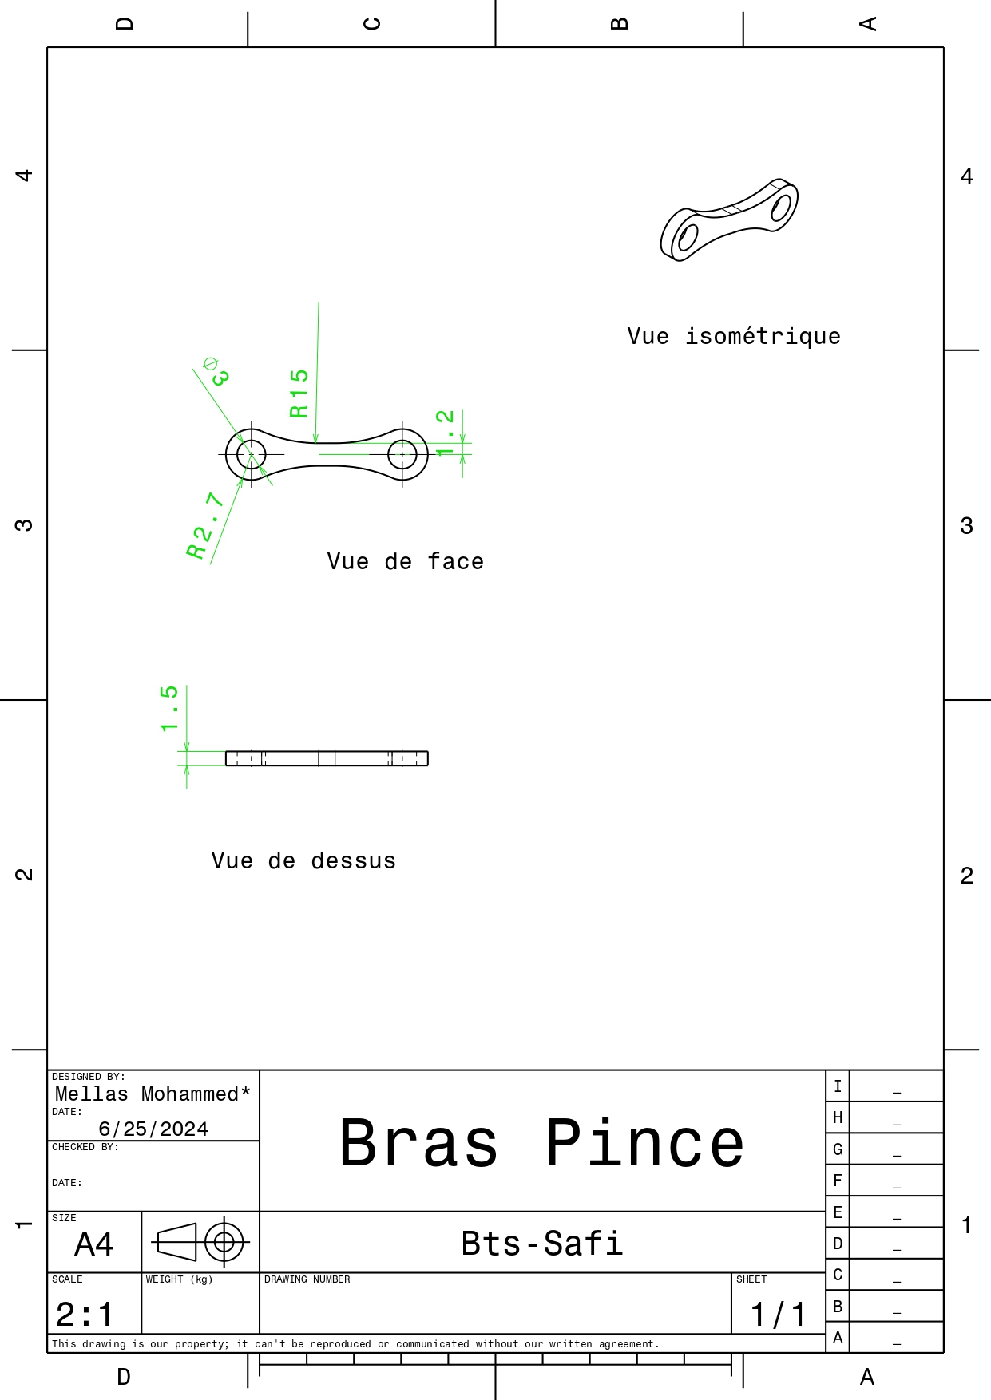
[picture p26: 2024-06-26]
Drawings/jpgs/Bras-Pince/Bras Pince_page-0001.jpg

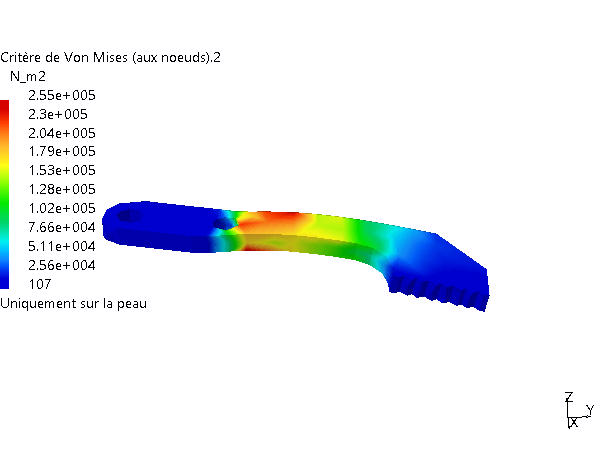
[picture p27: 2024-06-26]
analyse structurale/Pince/file3_667ac9f5.jpg

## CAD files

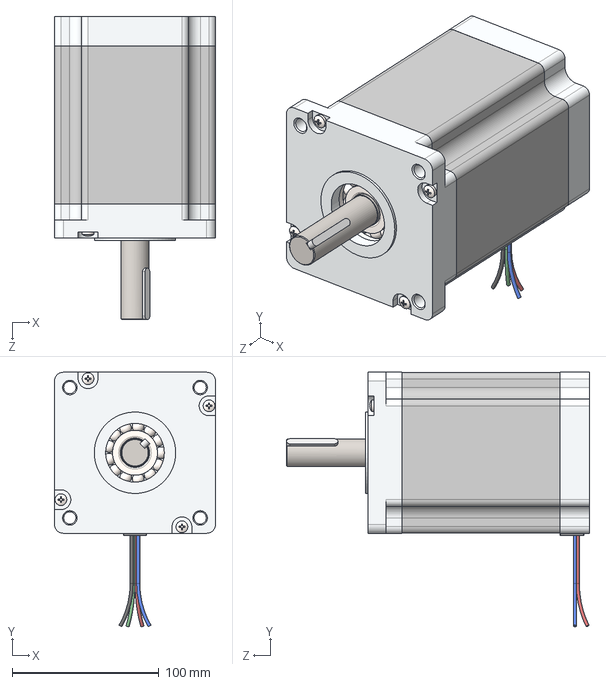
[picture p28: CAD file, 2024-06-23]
Assets for Presentation/Ctalogue/ML42HS2-3D-Model.step
109.8 x 173.6 x 206.6 mm

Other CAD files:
Assemblage Finale/Assemb.CATProduct
Assemblage Finale/Part20.CATPart
Assemblages/Assemb.CATProduct
Assemblages/Assemblage 0.CATProduct
Assemblages/Assemblage_BrasStatiques.CATProduct
Assemblages/Assemblage_Brasmobile_00et01.CATProduct
Assemblages/Car.CATProduct
Assemblages/Griper base.CATPart
Assemblages/ISO_4014_M4x30_STEEL_GRADE_A_HEXAGON_HEAD_BOLT.CATPart
Assemblages/ISO_7089_5x10_STEEL_GRADE_A_NORMAL_SERIES_PLAIN_WASHER.CATPart
Assemblages/Motor_0.CATProduct
Assemblages/Robot_Top.CATProduct
Assemblages/base rotatif + bras stataique.CATProduct
Assemblages/bras 2 rotatif.CATProduct
Assemblages/bras rotatif 2 du motor.CATPart
Assemblages/roue gripper.CATPart
BaseMobile.CATPart
BrasMobile_00.CATPart
Parts/Arber de Roue de Car base.CATPart
Parts/Arbre Motor_.CATPart
Parts/BRAS STATIQUE - MOTOR.CATPart
Parts/BRAS STATIQUE.CATPart
Parts/Base0.CATPart
Parts/BrasMobile_00.CATPart
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

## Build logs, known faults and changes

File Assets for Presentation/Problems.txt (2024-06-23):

high torque == high poids motor === solution gear box
high batrrei poids

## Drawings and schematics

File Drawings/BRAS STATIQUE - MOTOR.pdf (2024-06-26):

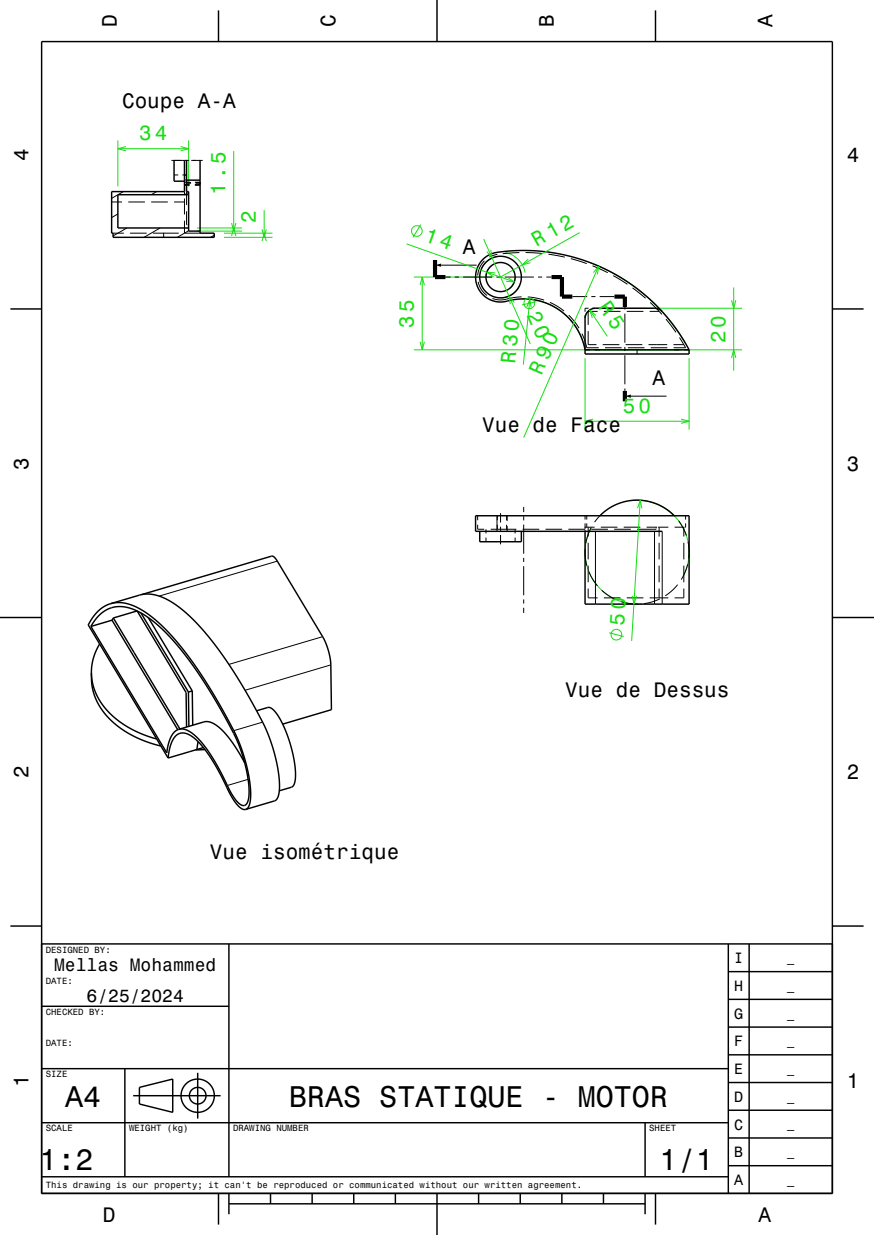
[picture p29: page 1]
CHECKED BY:; Coupe A-A; Vue isométrique

Vue de Face

Vue de Dessus

DESIGNED BY: Mellas Mohammed DATE: 6/25/2024 | I | _

SIZE A4 | | | | BRAS STATIQUE - MOTOR

SCALE 1:2 | WEIGHT (kg) | DRAWING NUMBER | SHEET 1/1

This drawing is our property; it can't be reproduced or communicated without our written agreement.

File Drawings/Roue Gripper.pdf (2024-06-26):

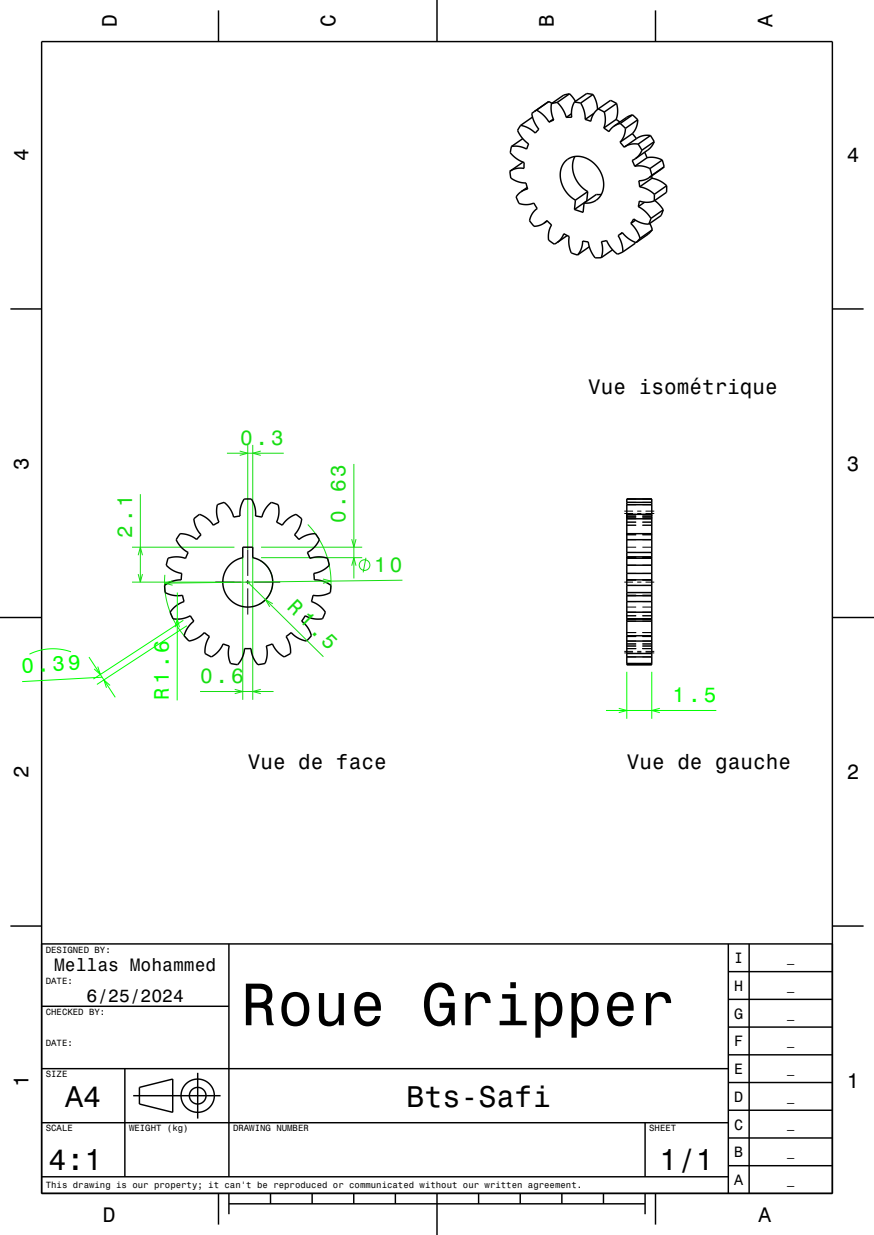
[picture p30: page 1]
CHECKED BY:; Vue isométrique

Vue de face

Vue de gauche

DESIGNED BY: Mellas Mohammed DATE: 6/25/2024 | Roue Gripper | I | _

SIZE A4 | | | | Bts-Safi

SCALE 4:1 | WEIGHT (kg) | DRAWING NUMBER | SHEET 1/1

This drawing is our property; it can't be reproduced or communicated without our written agreement.

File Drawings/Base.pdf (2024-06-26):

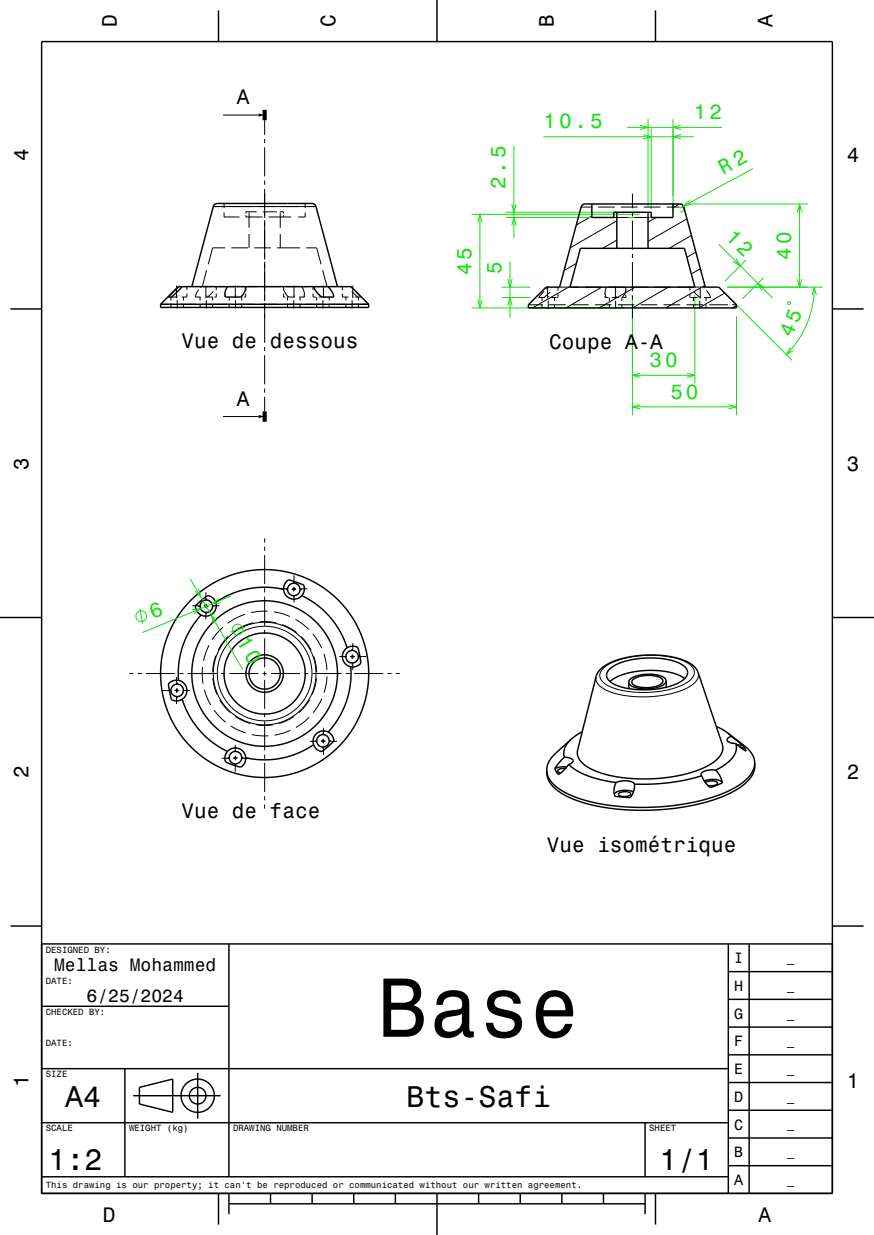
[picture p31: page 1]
CHECKED BY:; Vue de; dessous; Vue isométrique; Coupe A-A

Vue de face

DESIGNED BY: Mellas Mohammed 6/25/2024 DATE: | Base | I | _

SIZE A4 | | | | Bts-Safi

SCALE 1:2 | WEIGHT (kg) | DRAWING NUMBER | SHEET 1/1

This drawing is our property; it can't be reproduced or communicated without our written agreement.

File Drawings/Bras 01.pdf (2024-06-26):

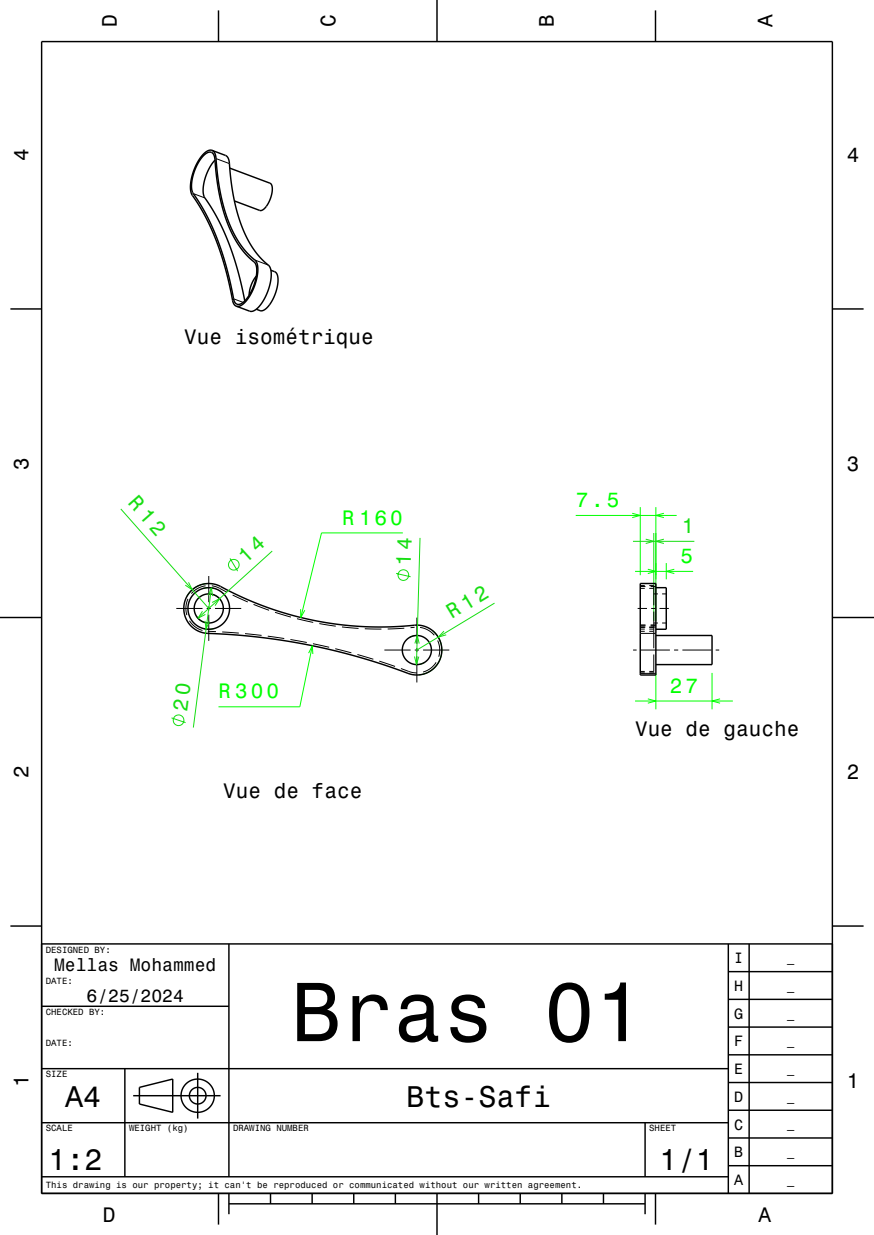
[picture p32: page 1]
CHECKED BY:; Vue isométrique

Vue de gauche

Vue de face

DESIGNED BY: Mellas Mohammed DATE: 6/25/2024 | Bras 01 | I | _

SIZE A4 | | | | Bts-Safi

SCALE 1:2 | WEIGHT (kg) | DRAWING NUMBER | SHEET 1/1

This drawing is our property; it can't be reproduced or communicated without our written agreement.

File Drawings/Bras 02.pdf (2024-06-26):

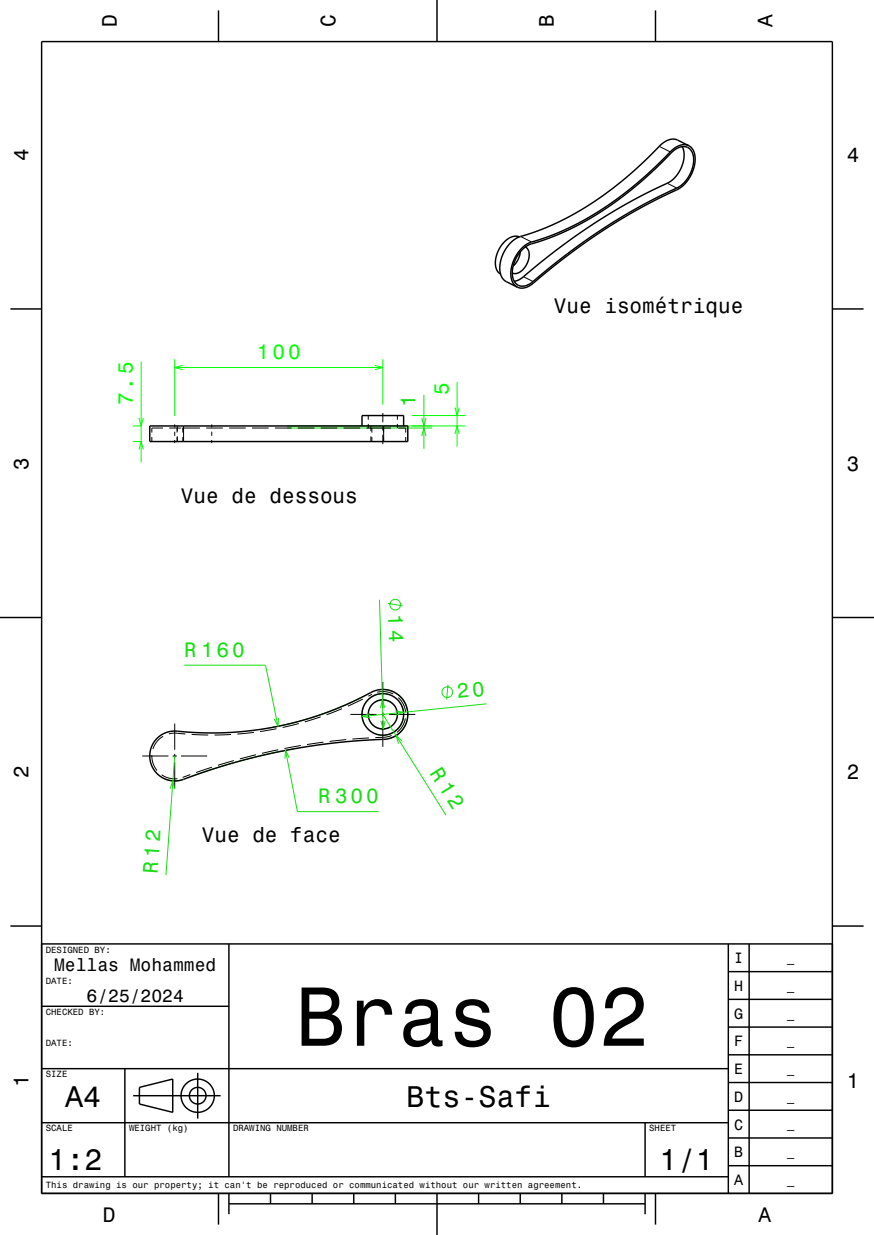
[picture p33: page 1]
CHECKED BY:; Vue isométrique

Vue de dessous

Vue de face

DESIGNED BY: Mellas Mohammed DATE: 6/25/2024 | Bras 02 | I | _

SIZE A4 | | | | Bts-Safi

SCALE 1:2 | WEIGHT (kg) | DRAWING NUMBER | SHEET 1/1

This drawing is our property; it can't be reproduced or communicated without our written agreement.

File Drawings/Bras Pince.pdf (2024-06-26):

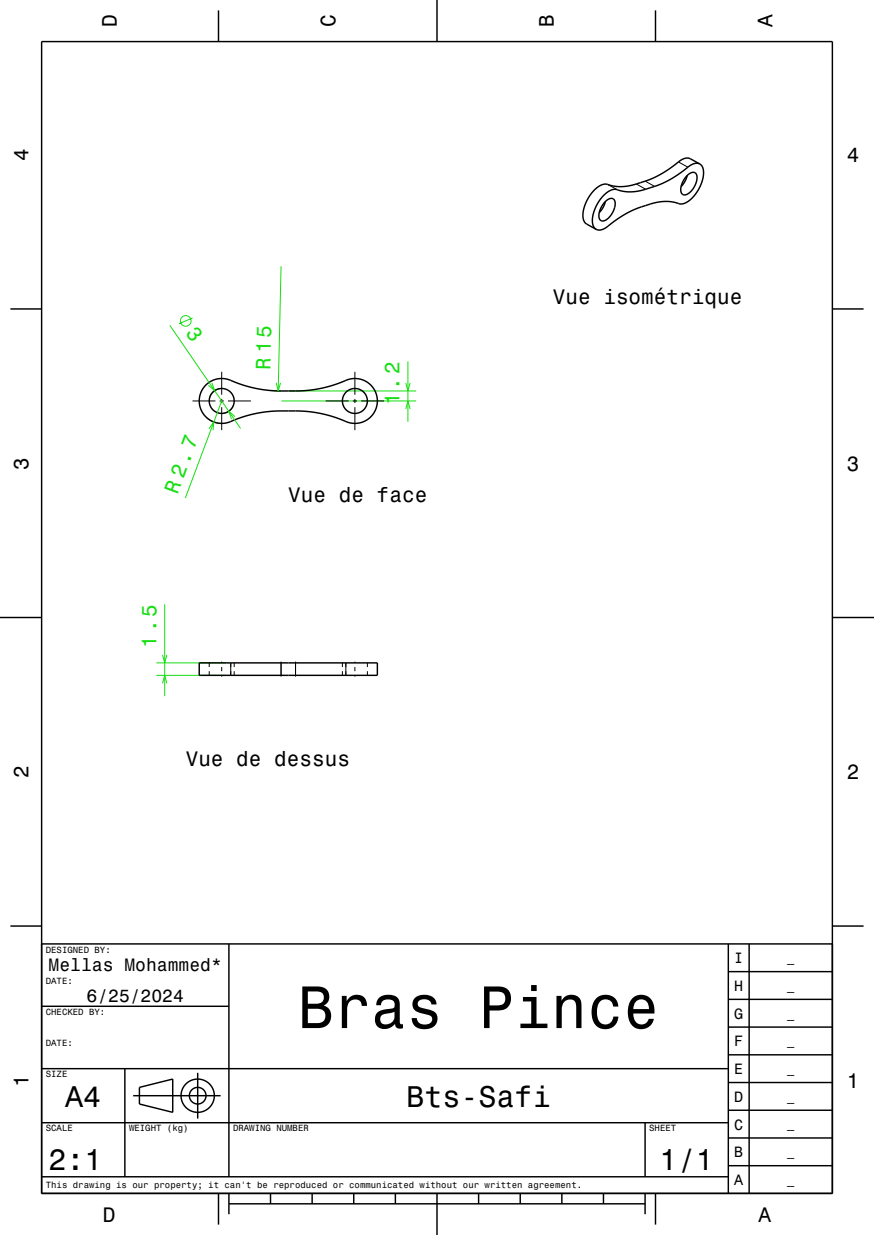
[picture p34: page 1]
CHECKED BY:; Vue isométrique

Vue de face

Vue de dessus

DESIGNED BY: Mellas Mohammed* 6/25/2024 DATE: | Bras Pince | I | _

SIZE A4 | | | | Bts-Safi

SCALE 2:1 | WEIGHT (kg) | DRAWING NUMBER | SHEET 1/1

This drawing is our property; it can't be reproduced or communicated without our written agreement.

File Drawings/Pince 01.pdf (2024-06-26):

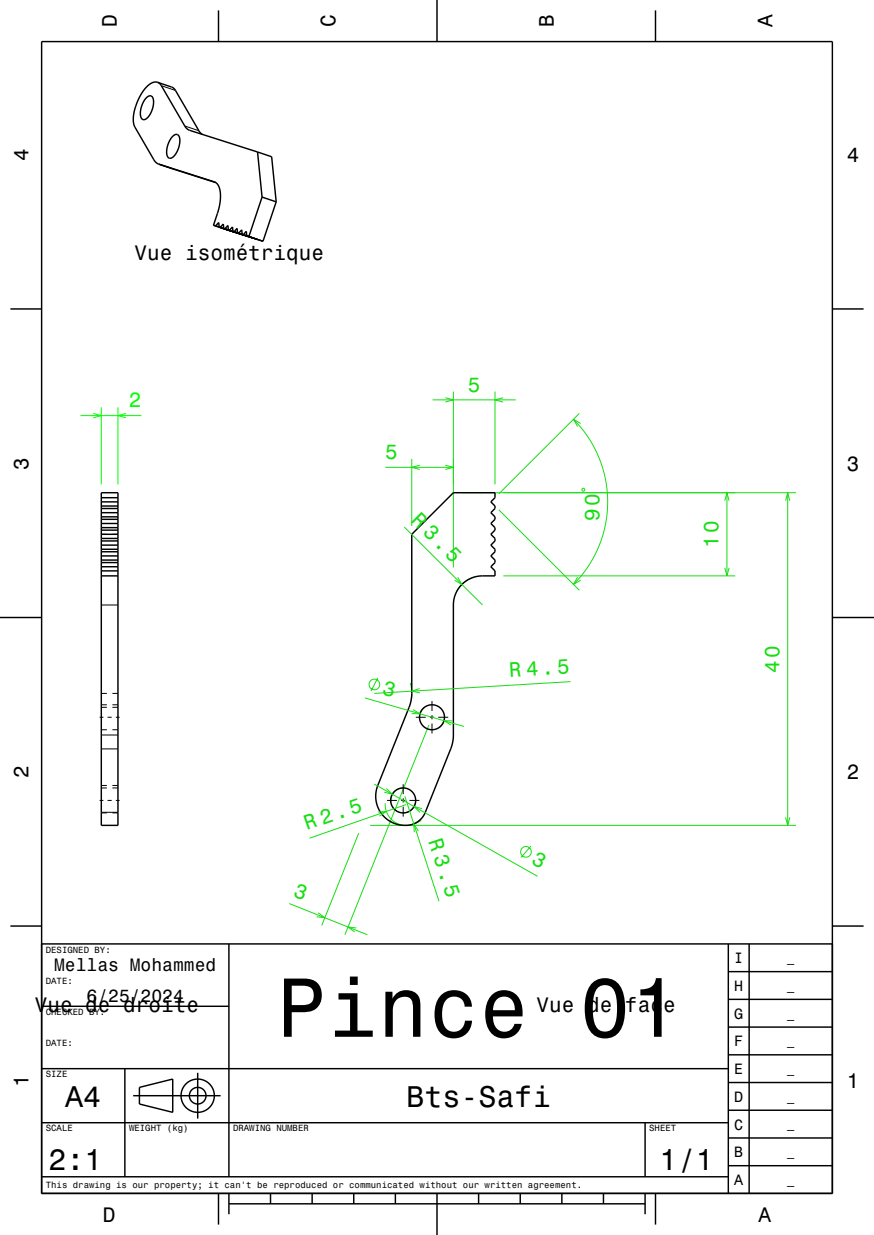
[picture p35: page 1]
Pince 01; Vue isométrique

DESIGNED BY:
Mellas Mohammed
Vue de droite
CHECKED BY:

Vue de face

SIZE A4 | | | | Bts-Safi

SCALE 2:1 | WEIGHT (kg) | DRAWING NUMBER | SHEET 1/1

This drawing is our property; it can't be reproduced or communicated without our written agreement.

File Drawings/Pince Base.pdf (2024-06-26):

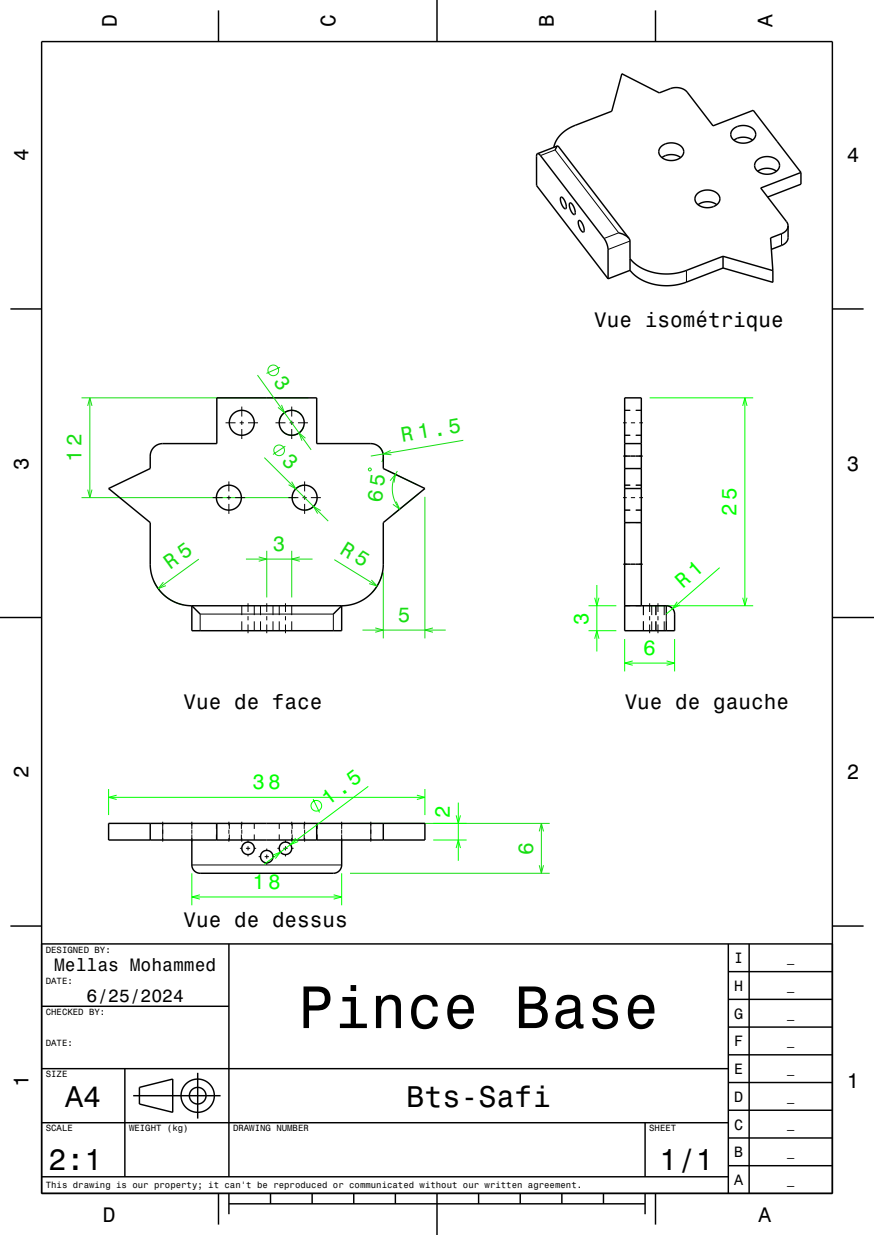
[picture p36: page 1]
CHECKED BY:; Vue isométrique

Vue de face

Vue de gauche

Vue de dessus

DESIGNED BY: Mellas Mohammed 6/25/2024 DATE: | Pince Base | I | _

SIZE A4 | | | | Bts-Safi

SCALE 2:1 | WEIGHT (kg) | DRAWING NUMBER | SHEET 1/1

This drawing is our property; it can't be reproduced or communicated without our written agreement.

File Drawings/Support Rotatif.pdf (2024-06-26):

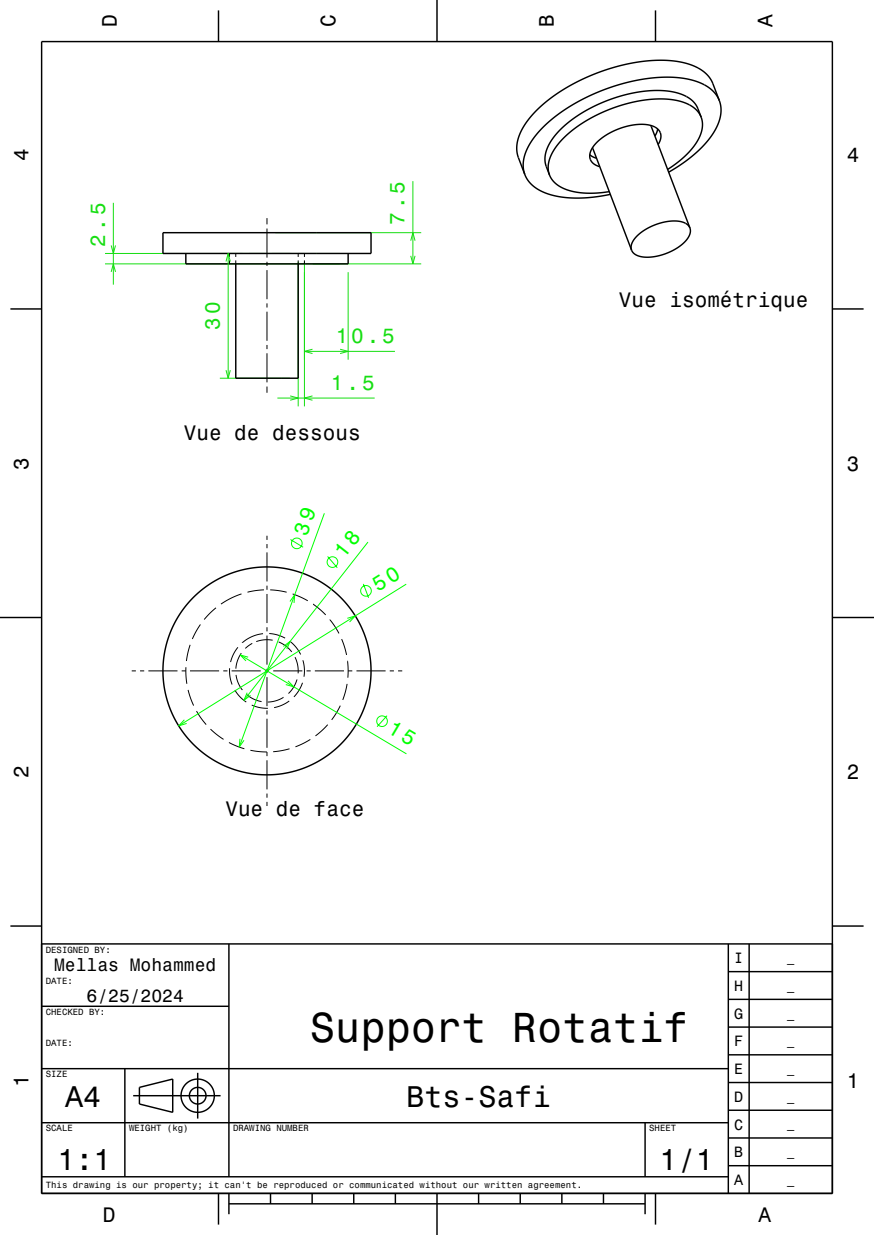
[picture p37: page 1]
CHECKED BY:; Vue isométrique

Vue de dessous

Vue de face

DESIGNED BY: Mellas Mohammed DATE: 6/25/2024 | Support Rotatif | I | _

SIZE A4 | | | | Bts-Safi

SCALE 1:1 | WEIGHT (kg) | DRAWING NUMBER | SHEET 1/1

This drawing is our property; it can't be reproduced or communicated without our written agreement.

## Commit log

2024-01-20 first push
    [Arbre Motor_.CATPart, Assemblage 0.CATProduct, Assemblage_BrasStatiques.CATProduct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]
2024-01-20 pince added
    [Robot_Top.CATProduct, bras rotatif 2 du motor.CATPart, gripper arm _pince.CATPart]
2024-02-24 prototype version : 1.0 Completed , car added
    [Arber de Roue de Car base.CATPart, Car.CATProduct, CarBase.CATPart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]
2024-06-26 Version 0.9.5
    [Griper base.CATPart, Part20.CATPart, ROBOT BLENDER STL - ROBOT BLENDER.stp-1 BRAS STATIQUE.1.stp-1.STL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]
2024-07-03 Version 1.0.0
    this version is not completed , but further updates will be coming soon to complete the Bluetooth things and so on.
    [Assemb.CATProduct, Base0.CATPart, ML42HS2-3D-Model.step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]
2024-09-23 Update README.md
    # HelperRobot
    building a robot that can do diffrent tasks in diffrent use cases
    # About
    this project is a BTS graduation project and as a mechanical product designers we had to come with a mechatronical mechanisme to inhance our knowledg
    # Help
    this project contains diffrent files extensions for diffrent software that has been used, y'll need :
    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
